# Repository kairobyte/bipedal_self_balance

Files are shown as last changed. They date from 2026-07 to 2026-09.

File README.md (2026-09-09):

# Bipedal Self Balancing Robot

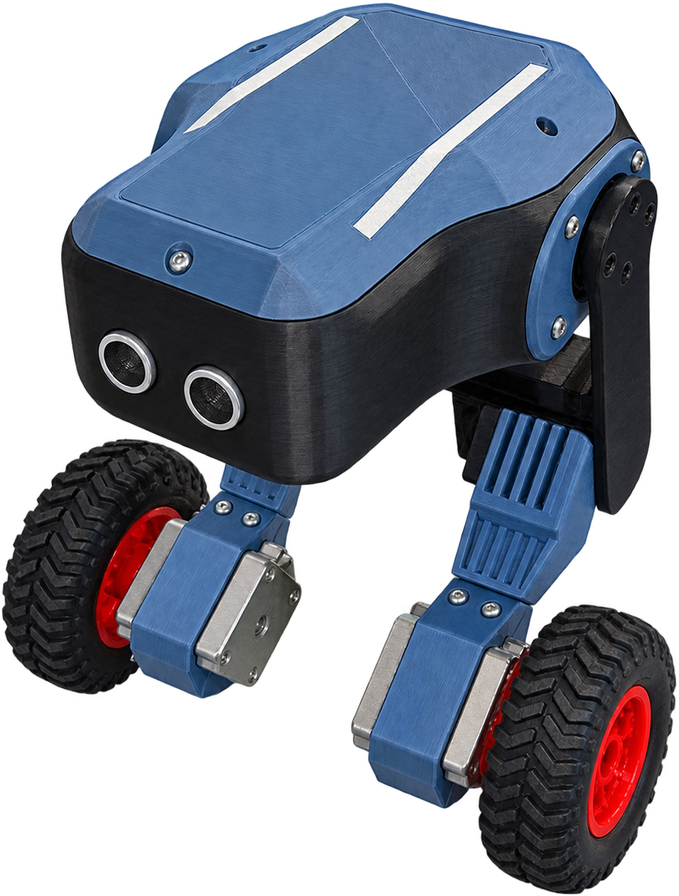
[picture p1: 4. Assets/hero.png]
Self Balancing Robot


## Introduction

This is a self-balancing robot built from scratch, 3D modeled, PCB designed, 3D printed, wired, and tuned entirely as a personal project. It uses an ESP32 as the main controller, dual IMUs for redundancy, stepper-driven wheels, and 2-DOF legs for lean control.

Right now, it balances for a few seconds at a time. It is not perfect, and there are known issues (see [Problems](#problems) below), but the full design, hardware, and firmware are open source here for anyone who wants to build on it, learn from it, or point out what I got wrong.

**Follow the Journey:** [@kairobyte](https://instagram.com/kairobyte) on Instagram.

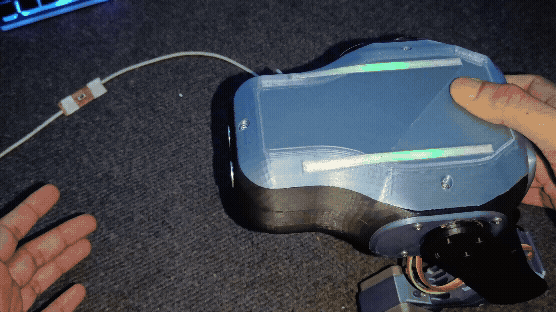
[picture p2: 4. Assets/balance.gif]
Balancing Video


## Sponsors

This build was supported by:

- **[NextPCB](https://www.nextpcb.com/?code=kairobyte)**: PCB manufacturing for this project. Upload your Gerber files, pick your color and thickness, and get an instant quote. Get $30 off your first order.
  
- **[Axis Tech](https://print3dnepal.com/)**: Provided 3D printing filament for this build. They also offer 3D printing services and build a wide range of custom projects. If you're local, check them out.

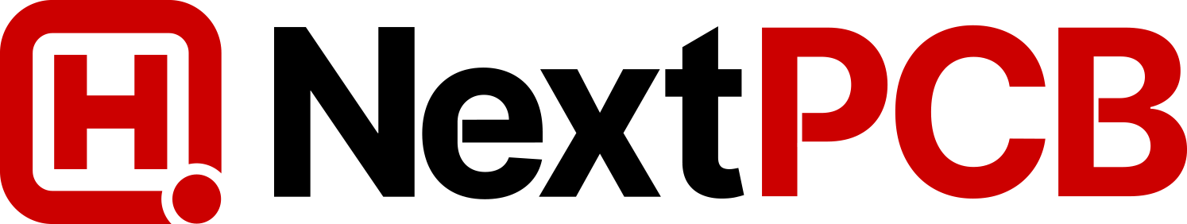
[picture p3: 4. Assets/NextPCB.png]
NextPCB Logo
[](https://www.nextpcb.com/?code=kairobyte)

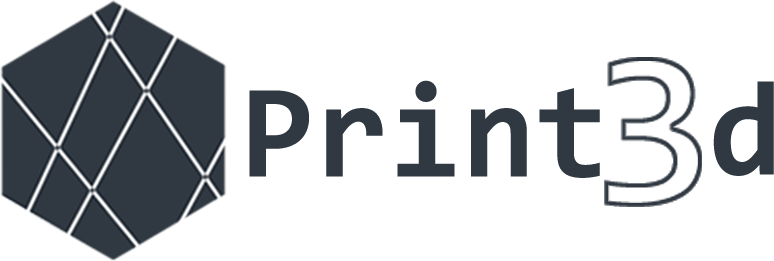
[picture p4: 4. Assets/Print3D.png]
Print3D Logo
[](https://print3dnepal.com/)

## Table of Contents

- [How It Started](#how-it-started)
- [Components](#components)
- [Electronics](#electronics)
- [PCB](#pcb)
- [3D Modelling](#3d-modelling)
- [3D Printing](#3d-printing)
- [Assembly](#assembly)
- [Firmware](#firmware)
- [PID Tuning](#pid-tuning)
- [Problems](#problems)
- [Result](#result)
- [Future Plans](#future-plans)
- [Repository Structure](#repository-structure)
- [License](#license)

## How It Started

- **Idea**: the initial concept for a self-balancing robot.
- **Sketch**: a rough hand sketch of the intended design.
- **Draft 3D Model**: a basic, non-functional 3D model built from the sketch, just for a rough scale and proportion estimate.

<!-- PLACEHOLDER: Sketch photo and early draft 3D model screenshot -->
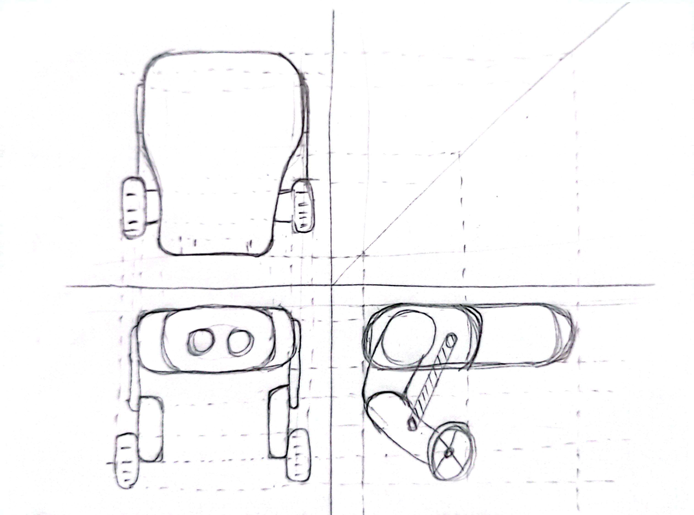
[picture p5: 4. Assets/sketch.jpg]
Rough Sketch
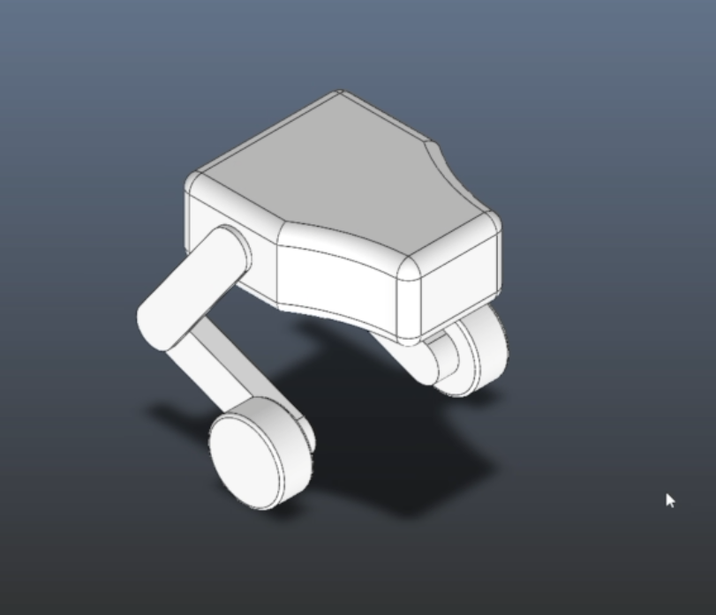
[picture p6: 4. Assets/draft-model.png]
Draft 3D Model


## Components

- **ESP32**: main controller.
- **MPU6050 + MPU9250**: dual IMUs, used for sensor redundancy.
- **A4988 Driver**: used to control the stepper motors.
- **Stepper motors**: used for wheel drive.

> **Note:** If you're building something similar, I would not recommend steppers for the wheels. Go with high-torque BLDC motors instead. Steppers work, but they're not the ideal choice here.

## Electronics

- Two buck converters step down 12V from a 3S LiPo battery, one dedicated to sensors, one dedicated to servos, to keep noisy current draw away from sensor power.
- A capacitor and diode protect the ESP32 from brownouts during high current draw from the servos and steppers.

## PCB

- Selected footprints and components, then built out the full schematic with labeled nets for readability.
- Completed layout and routing.
- Ran the Design Rule Checker (DRC), exported Gerber files, and had the board manufactured through [NextPCB](https://www.nextpcb.com/?code=kairobyte).

<!-- PLACEHOLDER: Schematic screenshot, PCB layout, and final manufactured board photo -->
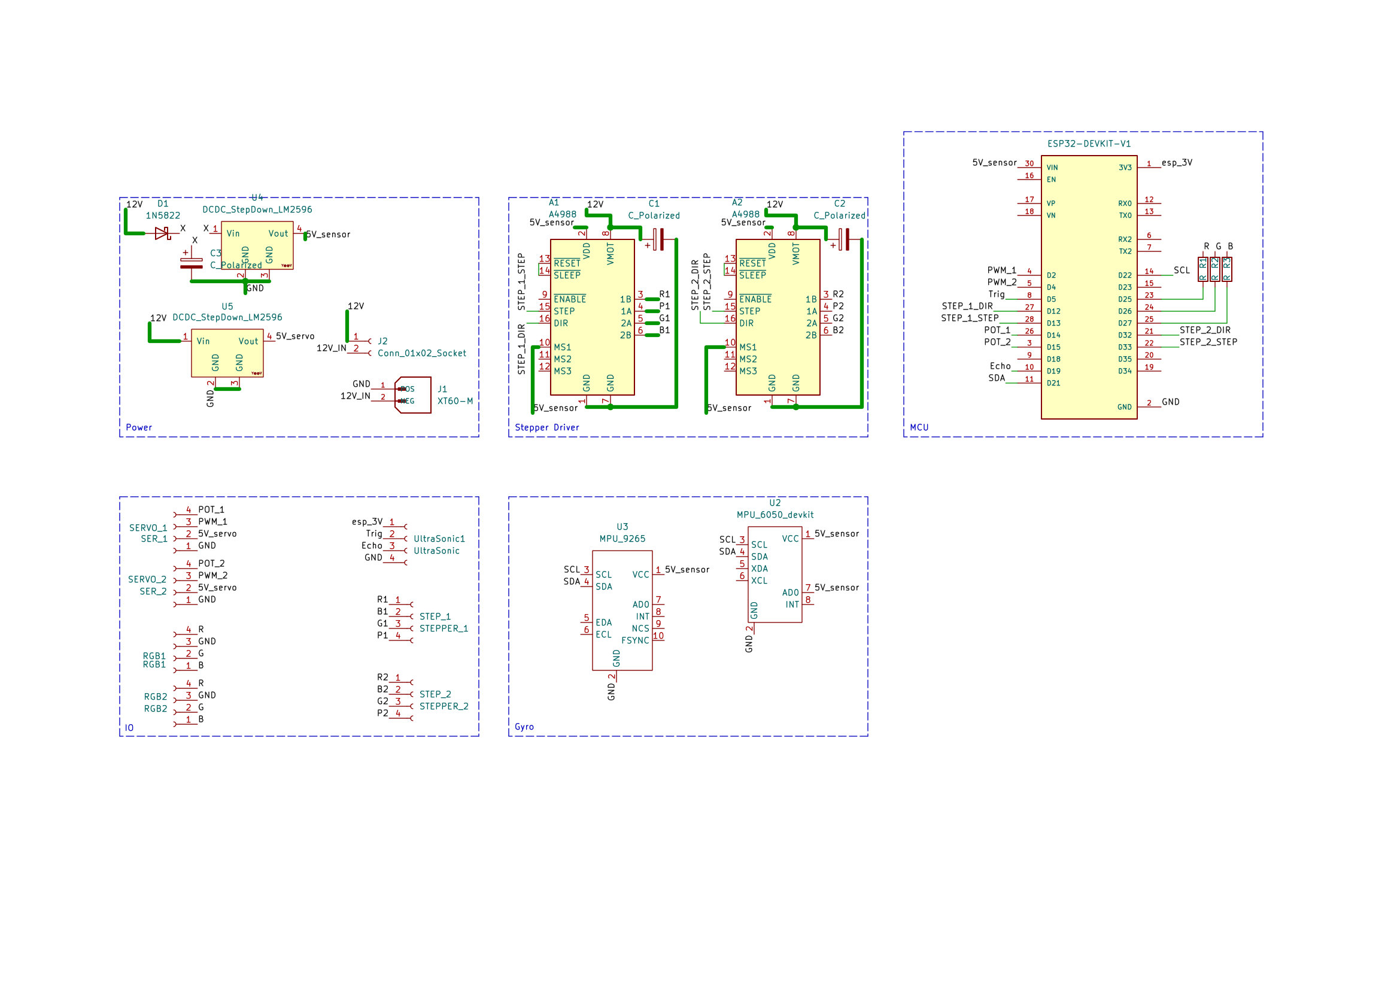
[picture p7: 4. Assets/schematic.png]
Schematic

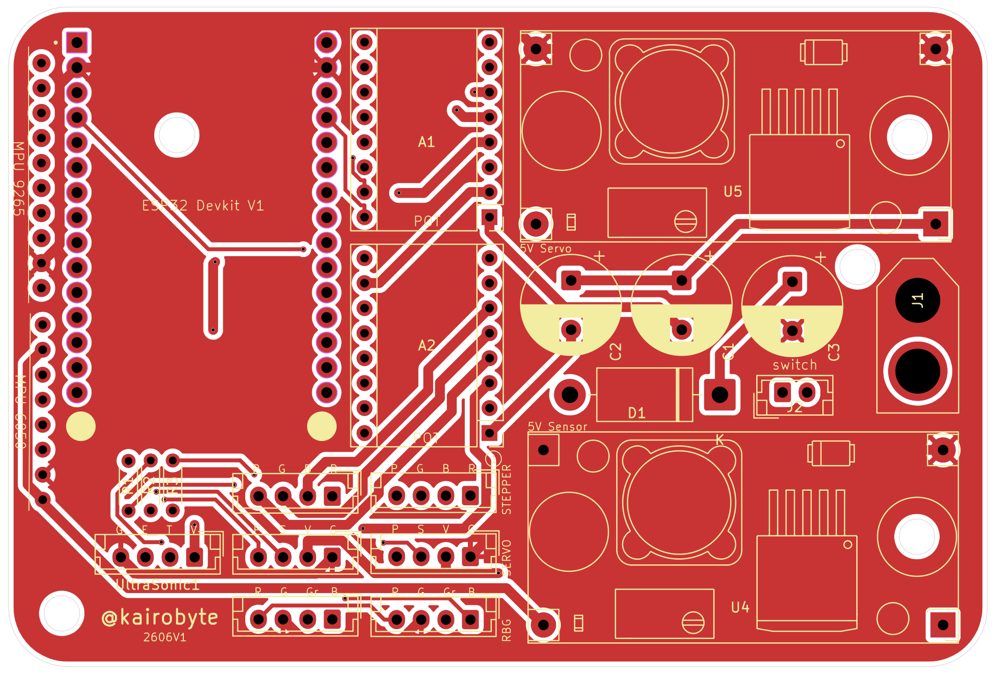
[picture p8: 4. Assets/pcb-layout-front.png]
PCB Layout Front

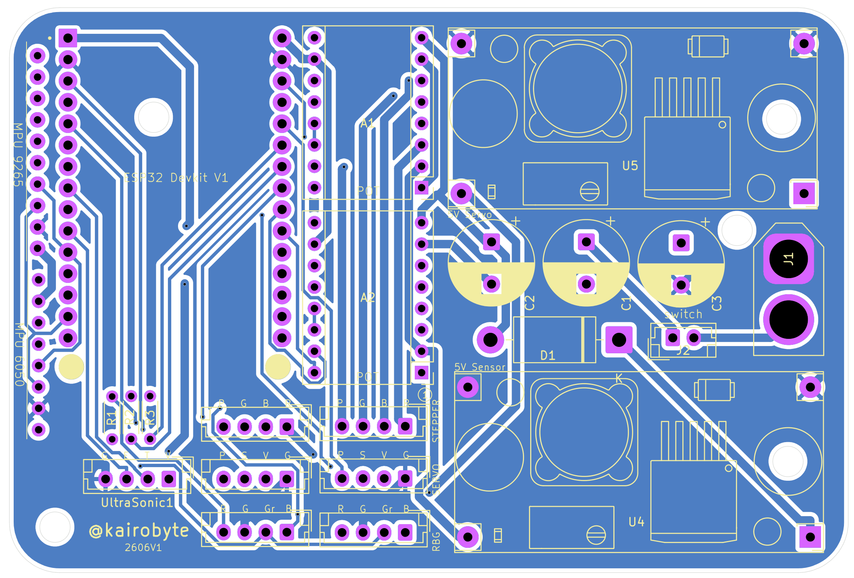
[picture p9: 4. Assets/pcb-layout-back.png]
PCB Layout Back

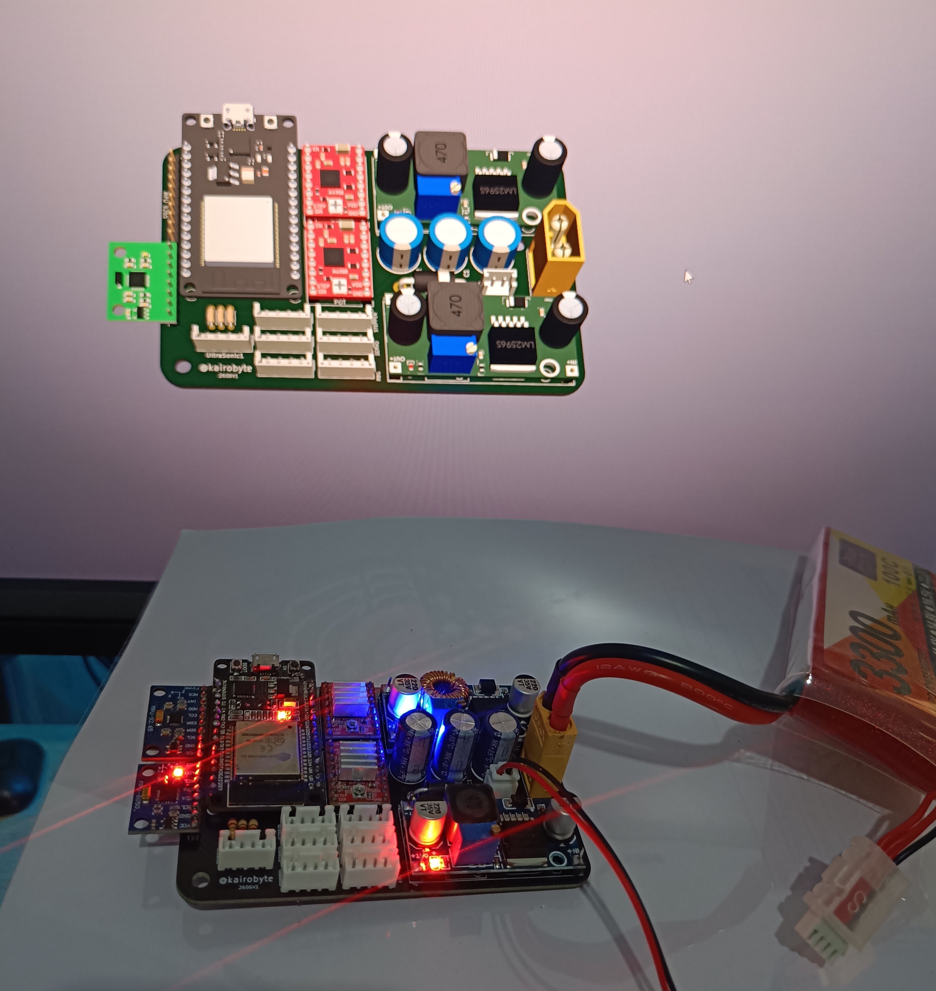
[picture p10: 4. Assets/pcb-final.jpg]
Final PCB


## 3D Modelling

- Modeled in SolidWorks, built bottom-up: stepper holders → legs → base.
- Every part was broken down into basic shapes and built up gradually.
- Designing for 3D printability is a different skill from designing for looks, significant time went into optimizing parts for print rather than just appearance.

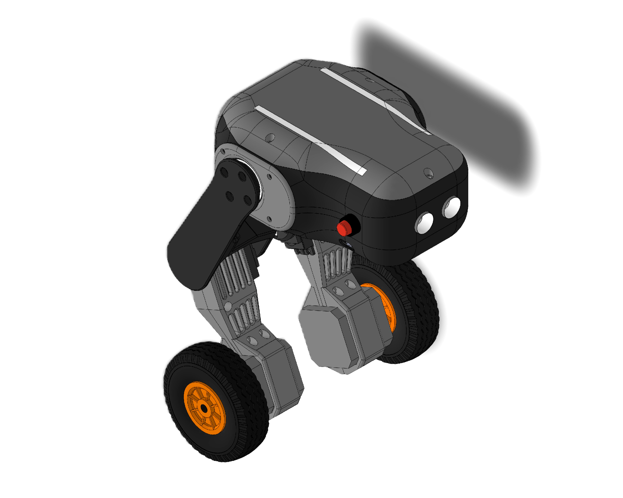
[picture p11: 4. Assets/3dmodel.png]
3D Model


## 3D Printing

- Parts were prepared and arranged in the slicer, then printed over several days.
- Most parts fit together correctly on the first attempt.
- Thanks [Axis Tech](https://print3dnepal.com/) for the Filament Support! 

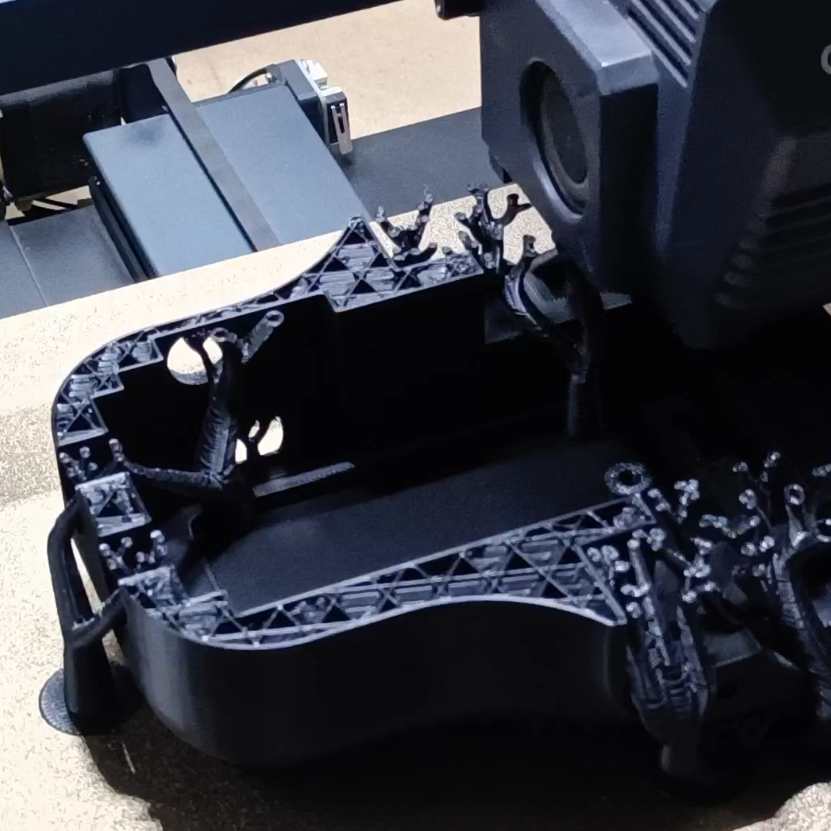
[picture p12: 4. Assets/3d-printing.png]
3D Printing Process


## Assembly

- Assembled all 3D printed parts and completed the wiring.
- The original plan was for 1 degree of freedom (DOF) per leg. When this changed to 2 DOF, extra wires had to be soldered directly onto the ESP32.

> **If you're building this yourself:** finalize your degrees of freedom before finalizing your board layout, to avoid needing extra hand-soldered connections.

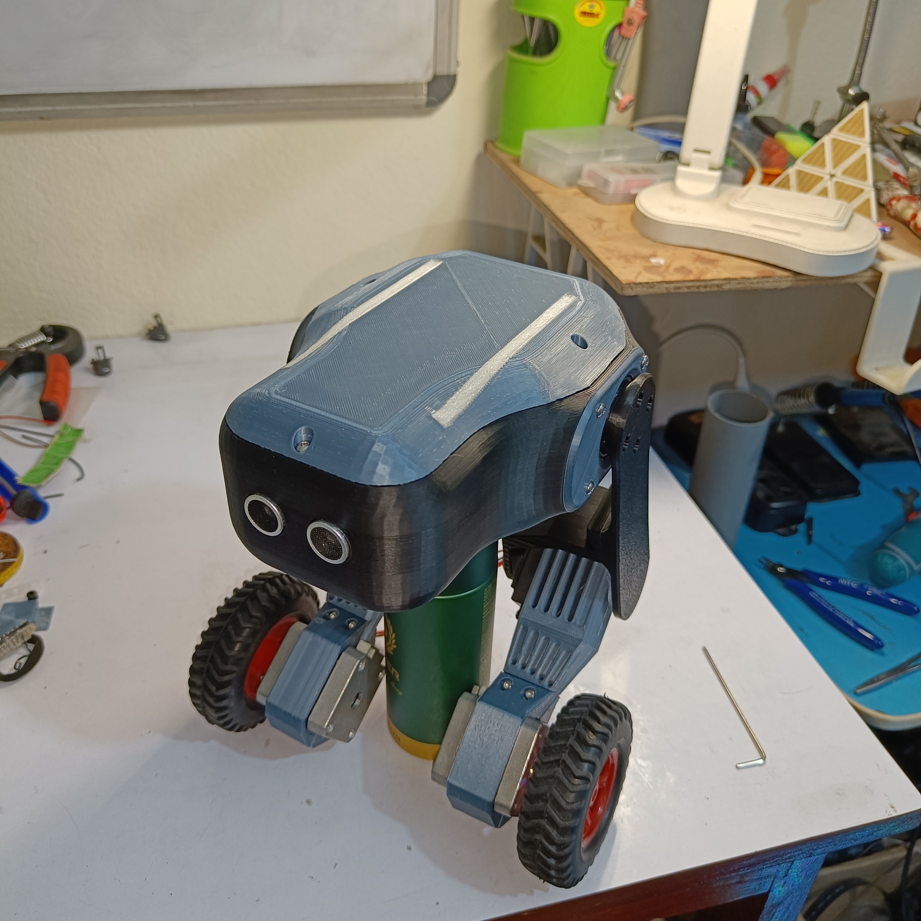
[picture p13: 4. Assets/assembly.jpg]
Fully Assembled Build


## Firmware

- Ran initial test code to confirm all motors, sensors, and RGB indicators were functioning correctly.
- Built a basic PID controller as the first control approach.
- Due to the robot's irregular shape, finding the correct center of mass, and therefore the correct PID set point, was one of the most time-consuming parts of the build.

## PID Tuning

Tuning was the hardest part of this project by a significant margin.

- Initially tuned by manually guessing parameters and reflashing the ESP32 for every change, slow and impractical.
- Updated the firmware to accept tuning parameters over serial and save them without requiring a reflash. A WiFi-based version was attempted but caused repeated ESP32 brownout warnings, so serial was used instead.
- After a couple of days with no visible progress, found that one servo was vibrating irregularly and injecting significant noise into the sensor readings. Replacing that servo noticeably improved stability, though it wasn't a complete fix.
- After continued tuning, the robot balanced for the first time, for a few seconds.
- Found that linear gain increments were not effective, and switched to exponentially increasing gains, along with a low-pass filter applied to key parameters. This slowed the robot's reaction time somewhat, but the control loop still ran at approximately 1kHz, which was fast enough to remain effective.
- Total PID tuning time was a little over a week, including a short break after becoming frustrated with a lack of progress.

## Problems

- **Servo speed**: current servos aren't fast enough to keep up with PID output; the actuator consistently lags behind the commanded position. Needs a faster servo, or a BLDC motor with gear reduction.
- **PID tuning method**: manually guessing parameters is slow and inefficient; a more systematic tuning approach would be better.
- **Vibration/noise**: servo vibration was a major source of sensor noise and nearly derailed the project. Replacing the affected servo helped significantly.
- **Electronics/compute headroom**: the ESP32 currently handles the full control loop, but adding Bluetooth communication (for planned PS4 controller support) is expected to consume enough clock cycles to slow down the PID loop. A better long-term architecture would use a dedicated microcontroller (e.g. STM32) for the core PID loop, with the ESP32 handling WiFi/Bluetooth communication separately, connected via UART.
- **Noise/sensing**: relying on a single sensing source is fragile. A low-pass filter helps smooth spikes, and vibration-dampening rubber mounts can reduce mechanical noise from the steppers.

## Result

The robot currently balances for a few seconds before losing stability. It is a working proof of concept, not a finished product, further tuning and hardware changes are planned for the next phase of this build.

## Future Plans

- **PS4 controller integration** over Bluetooth.
- **Machine learning-based balancing**: exploring whether an ML approach could replace or supplement the PID controller. This is unexplored territory for this project so far.

Follow along on Instagram for more frequent build updates.

## Repository Structure

<!-- PLACEHOLDER: adjust to match your actual repo layout -->
```
├── 1. 3D_Model               # SolidWorks source files and exported STLs
├── 2. PCB_Design             # Schematic, PCB layout, and Gerber files
├── 3. Code                   # ESP32 source code
├── 4. Assets                 # Images used in this README
├── LICENSE
└── README.md
```

## License

This project is open source under the MIT license. See `LICENSE` for details.

##

Send a mail if you want to discuss robotics, design, engineering projects, or anything you think I should build next.
[mail@sushant.uk](mailto:mail@sushant.uk)

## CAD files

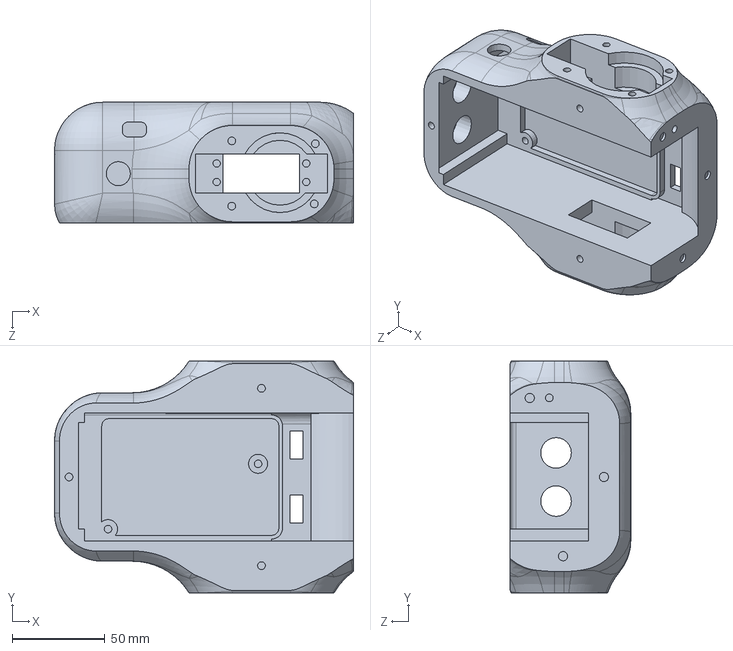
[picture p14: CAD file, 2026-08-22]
1. 3D_Model/2_Body/main.SLDPRT
161.2 x 125.0 x 65.0 mm

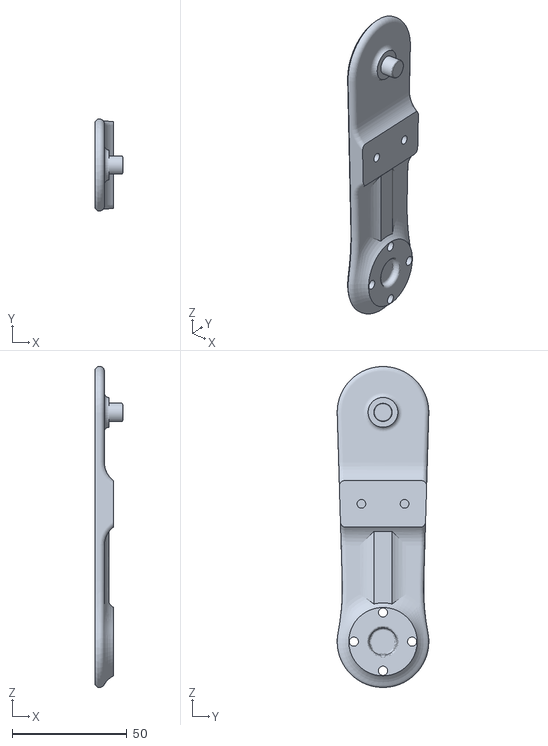
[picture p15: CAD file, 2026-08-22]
1. 3D_Model/3_Upper_Leg/stl/Upper_Leg_CouplerMirror.STL
12.0 x 40.0 x 140.0

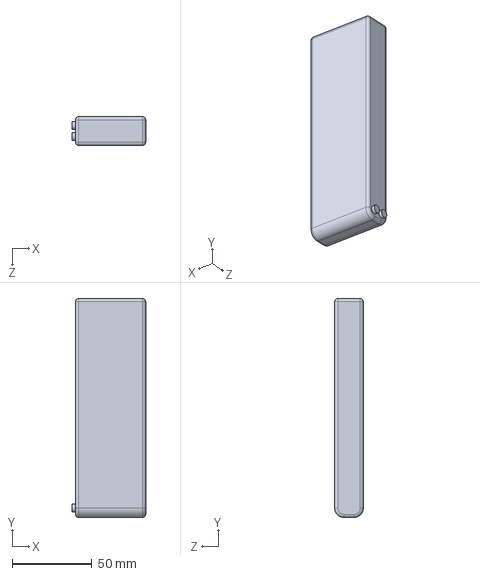
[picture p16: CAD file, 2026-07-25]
1. 3D_Model/7_Accessories/LiPo_Battery.SLDPRT
46.0 x 137.0 x 18.0 mm

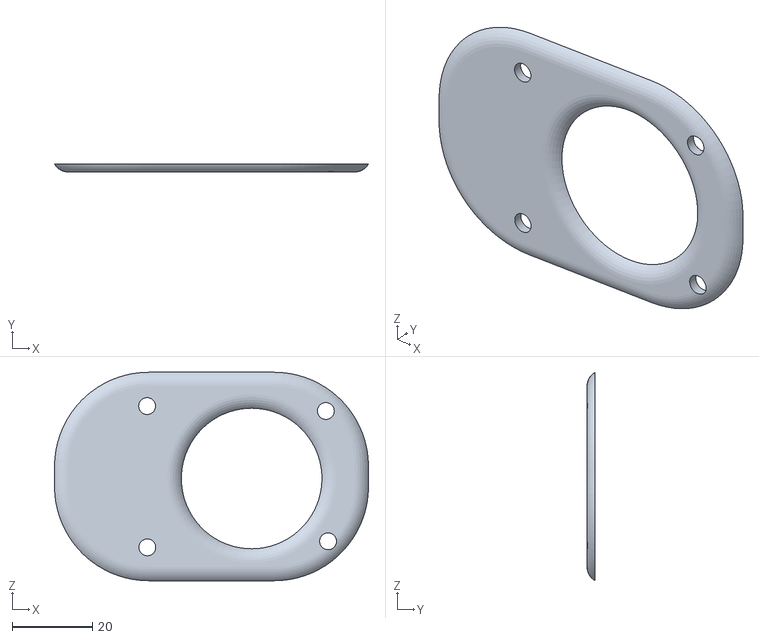
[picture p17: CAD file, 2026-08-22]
1. 3D_Model/8_stl/base_cover_left.STL
78.2 x 2.00 x 51.9

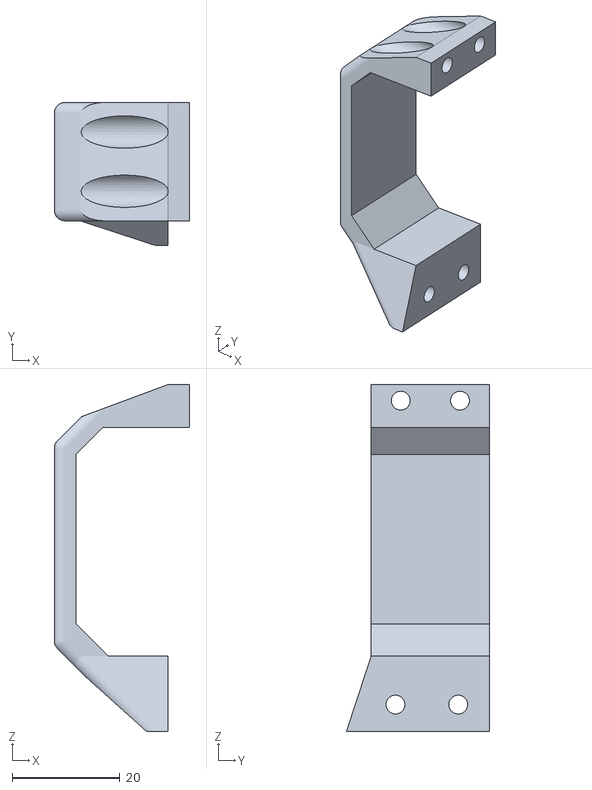
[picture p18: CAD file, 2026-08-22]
1. 3D_Model/8_stl/lower_leg/Lower_Leg_Step_HolderMirror.STL
25.1 x 26.6 x 64.4

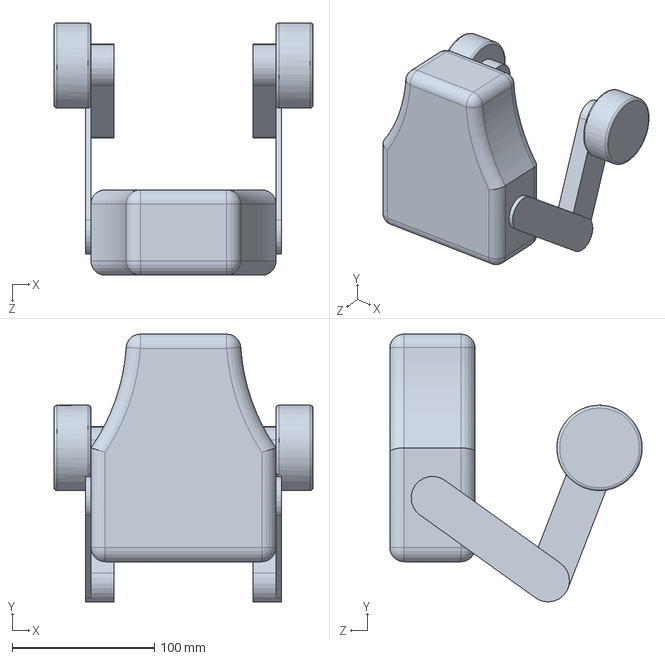
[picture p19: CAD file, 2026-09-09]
1. 3D_Model/basic.SLDPRT
182.0 x 188.2 x 177.4 mm

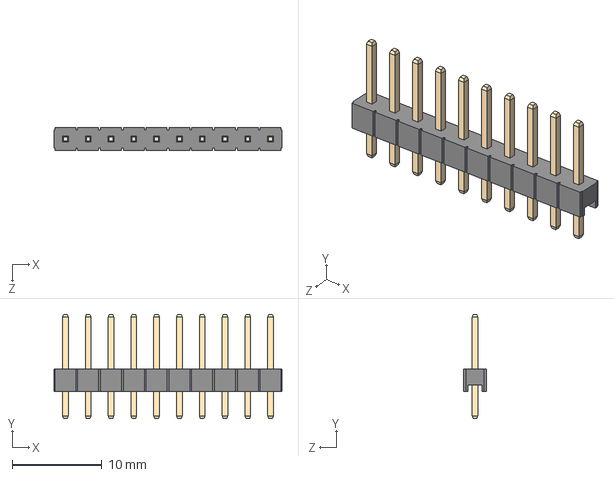
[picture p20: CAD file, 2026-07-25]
2. PCB_Design/0_Custom_Components/10_Pin_Header_Male.STEP
25.4 x 11.6 x 2.54 mm

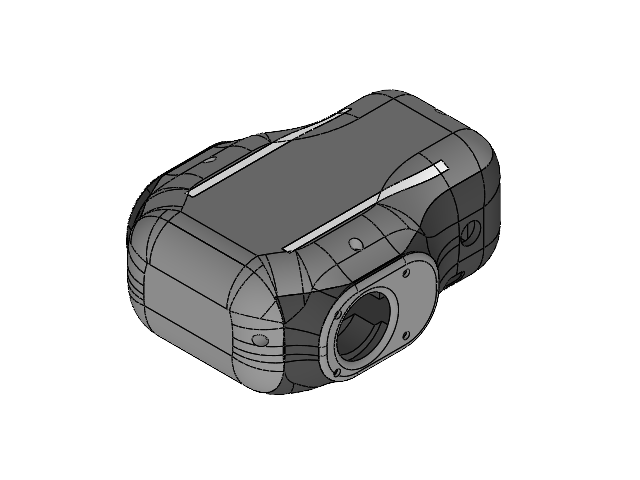
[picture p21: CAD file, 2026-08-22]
1. 3D_Model/2_Body/base.SLDASM
left
back
right
rgb_right
rgb_left
cover_top
main

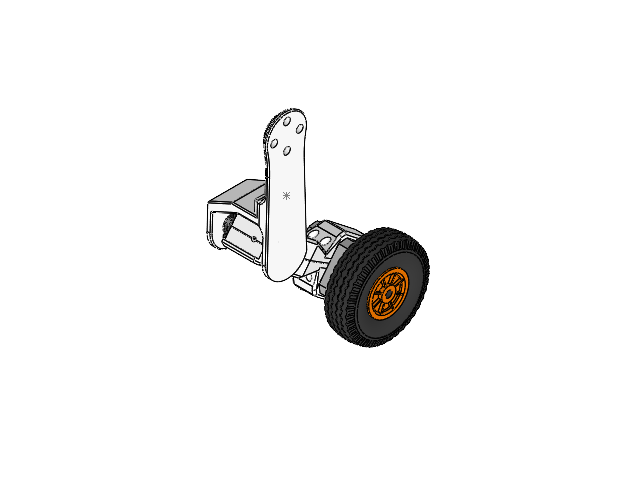
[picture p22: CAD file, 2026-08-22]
1. 3D_Model/3_Upper_Leg/Upper_Leg_Asm.SLDASM
NEMA 17 Motor.step
Scaled_Down_Wheel
MG996R_servo
Lower_Leg_Core
2026-04-08-22-59-56-753.step
2026-04-08-23-06-36-305.step
2026-04-08-23-12-16-735.step
2026-04-08-23-11-13-941.step
2026-04-08-23-50-19-770.step
2026-04-08-23-50-31-866.step
2026-04-08-23-50-38-288.step
2026-04-08-23-50-44-156.step
2026-04-08-23-50-48-451.step
2026-04-08-23-50-52-337.step
2026-04-08-23-59-55-520.step
2026-04-09-00-09-15-499.step
Lower_Leg_Core_Mirror
Lower_Leg_Step_Holder_Mirror
Lower_Leg_Step_Holder
Servo_Star_horn
Upper_Leg_Coupler
Upper_Leg_T

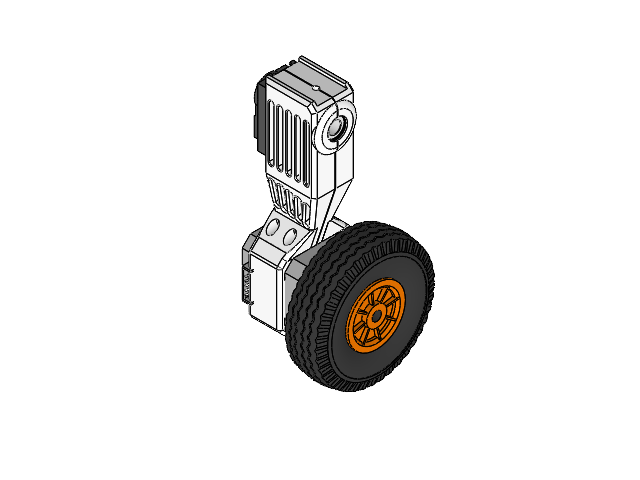
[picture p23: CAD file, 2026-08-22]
1. 3D_Model/4_Lower_Leg/Lower_Leg_Asm.SLDASM
NEMA 17 Motor.step
Scaled_Down_Wheel
MG996R_servo
Lower_Leg_Core
2026-04-08-22-59-56-753.step
2026-04-08-23-06-36-305.step
2026-04-08-23-12-16-735.step
2026-04-08-23-11-13-941.step
2026-04-08-23-50-19-770.step
2026-04-08-23-50-31-866.step
2026-04-08-23-50-38-288.step
2026-04-08-23-50-44-156.step
2026-04-08-23-50-48-451.step
2026-04-08-23-50-52-337.step
2026-04-08-23-59-55-520.step
2026-04-09-00-09-15-499.step
Lower_Leg_Core_Mirror
Lower_Leg_Step_Holder_Mirror
Lower_Leg_Step_Holder

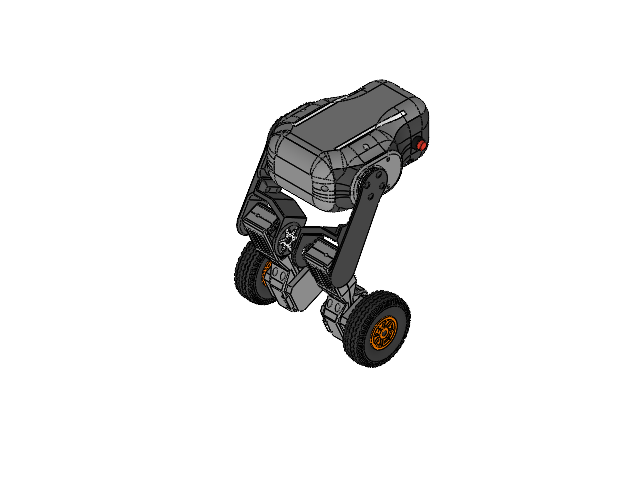
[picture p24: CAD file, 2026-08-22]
1. 3D_Model/main.SLDASM
YAAJ_DCDC_StepDown_LM2596_PinHeaders_cp-0_1.step x 2
JST_B4B_EH_A_1.step x 7
R_Axial_DIN0204_L36mm_D16mm_P508mm_Horizontal_1.step x 3
DS1021-1_10SF11_1.step
CP_Radial_D100mm_P500mm_1.step x 3
D_DO-201AD_P15.24mm_Horizontal-1_1.step
JST_B2B_EH_A_1.step
XT60 male v9_1.step
Document_1.step x 2
ESP32-DEVKIT-V1-2_1.step
Base_1.step
pin header_1.step x 8
sensor chip_1.step
S2NH chip_1.step
Resistor small_1.step x 6
Resistor small black_1.step x 4
Small LED_1.step
Resistor black_1.step
Controller_Board_PCB_1.step
HC-SR04
LiPo_Battery
68062RS.stp x 2
Servo_Horn x 2
coupler_servo_side x 2
PushButtonSwitch.step
NEMA 17 Motor.step
Scaled_Down_Wheel
MG996R_servo x 3
Lower_Leg_Core
2026-04-08-22-59-56-753.step
2026-04-08-23-06-36-305.step
2026-04-08-23-12-16-735.step
2026-04-08-23-11-13-941.step
2026-04-08-23-50-19-770.step
2026-04-08-23-50-31-866.step
2026-04-08-23-50-38-288.step
2026-04-08-23-50-44-156.step
2026-04-08-23-50-48-451.step
2026-04-08-23-50-52-337.step
2026-04-08-23-59-55-520.step
2026-04-09-00-09-15-499.step
Lower_Leg_Core_Mirror
Lower_Leg_Step_Holder_Mirror
Lower_Leg_Step_Holder
Servo_Star_horn
Upper_Leg_Coupler
Upper_Leg_T
left
back
right
rgb_right
rgb_left
cover_top
main
NEMA 17 Motor.stepMirror
Scaled_Down_WheelMirror
MG996R_servoMirror
Lower_Leg_CoreMirror
2026-04-08-22-59-56-753.stepMirror
2026-04-08-23-06-36-305.stepMirror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

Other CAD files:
1. 3D_Model/3_Upper_Leg/mirrored_components/Upper_Leg_AsmMirror.SLDASM
1. 3D_Model/4_Lower_Leg/MirrorLower_Leg_Asm.SLDASM
1. 3D_Model/3_Upper_Leg/mirrored_components/Lower_Leg_AsmMirror.SLDASM
1. 3D_Model/3_Upper_Leg/mirrored_components/608RS Steel Ball Bearing.stepMirror.SLDASM
1. 3D_Model/1_External_Components/MirrorServo_Star_horn.SLDPRT
1. 3D_Model/3_Upper_Leg/mirrored_components/2026-04-08-23-50-31-866.stepMirror.SLDPRT
1. 3D_Model/8_stl/upper_leg/Upper_Leg_T.STL
1. 3D_Model/1_External_Components/608RS Steel Ball Bearing.step
1. 3D_Model/1_External_Components/68062RS.stp
1. 3D_Model/1_External_Components/85mm_Wheel.SLDPRT
1. 3D_Model/1_External_Components/HC-SR04.SLDPRT
1. 3D_Model/1_External_Components/MG996R_servo.SLDPRT
1. 3D_Model/1_External_Components/MirrorMG996R_servo.SLDPRT
1. 3D_Model/1_External_Components/MirrorNEMA 17 Motor.step
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

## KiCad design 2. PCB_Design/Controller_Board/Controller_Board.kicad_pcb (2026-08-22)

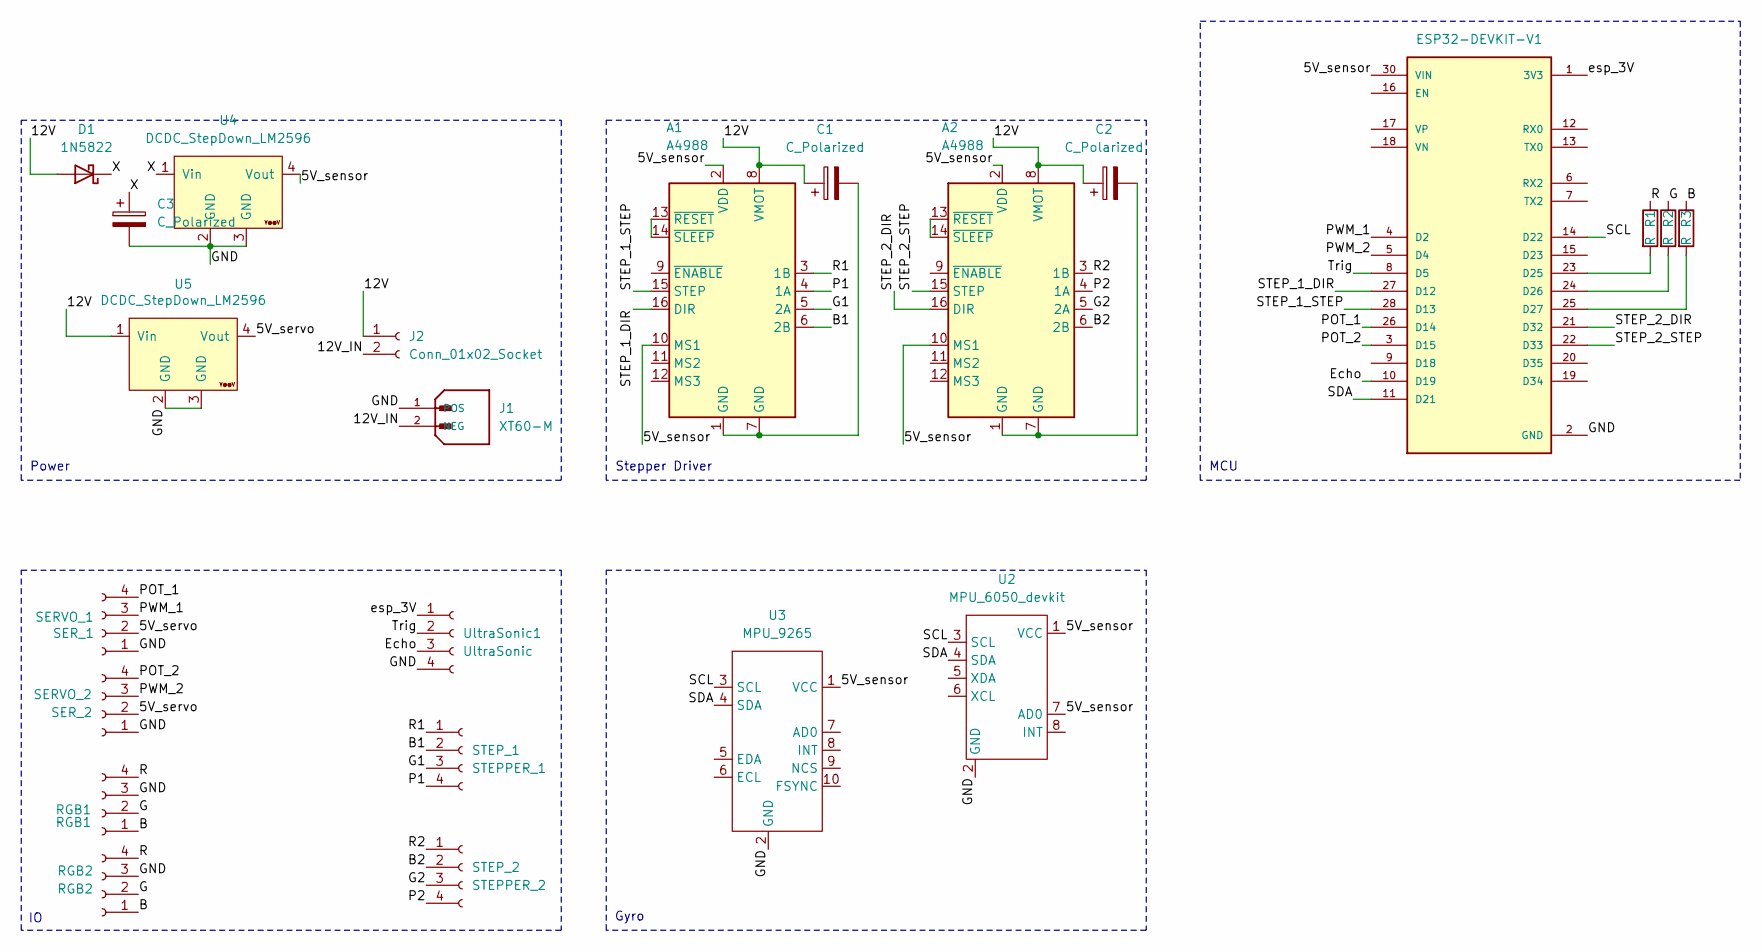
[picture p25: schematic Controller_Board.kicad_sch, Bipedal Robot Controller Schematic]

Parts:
A1, A2: A4988; Pololu_Breakout-16_15.2x20.3mm
C1, C2, C3: C_Polarized; CP_Radial_D10.0mm_P5.00mm
D1: 1N5822; D_DO-201AD_P15.24mm_Horizontal
J1: XT60-M; AMASS_XT60-M_1x02_P7.20mm_Vertical
J2: Conn_01x02_Socket; JST_EH_B2B-EH-A_1x02_P2.50mm_Vertical
R1, R2, R3: R; R_Axial_DIN0204_L3.6mm_D1.6mm_P5.08mm_Horizontal
RGB1: RGB1; JST_EH_B4B-EH-A_1x04_P2.50mm_Vertical
RGB2: RGB2; JST_EH_B4B-EH-A_1x04_P2.50mm_Vertical
SER_1: SERVO_1; JST_EH_B4B-EH-A_1x04_P2.50mm_Vertical
SER_2: SERVO_2; JST_EH_B4B-EH-A_1x04_P2.50mm_Vertical
STEP_1: STEPPER_1; JST_EH_B4B-EH-A_1x04_P2.50mm_Vertical
STEP_2: STEPPER_2; JST_EH_B4B-EH-A_1x04_P2.50mm_Vertical
U1: ESP32-DEVKIT-V1; MODULE_ESP32_DEVKIT_V1; PARTREV N/A
U2: MPU_6050_devkit; mpu_6050_custom
U3: MPU_9265; mpu_9265
U4, U5: DCDC_StepDown_LM2596; YAAJ_DCDC_StepDown_LM2596
UltraSonic1: UltraSonic; JST_EH_B4B-EH-A_1x04_P2.50mm_Vertical

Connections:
/5V_sensor: A1.2 (VDD), A1.10 (MS1), A2.2 (VDD), A2.10 (MS1), U1.30 (VIN), U2.1 (VCC), U2.7 (AD0), U3.1 (VCC), U4.4 (Vout)
/5V_servo: SER_1.2, SER_2.2, U5.4 (Vout)
/12V: A1.8 (VMOT), A2.8 (VMOT), C1.1, C2.1, D1.2 (A), J2.1, U5.1 (Vin)
/12V_IN: J1.2 (NEG), J2.2
/B: R3.1, RGB1.1, RGB2.1
/B1: A1.6 (2B), STEP_1.2
/B2: A2.6 (2B), STEP_2.2
/Echo: U1.10 (D19), UltraSonic1.3
/G: R2.1, RGB1.2, RGB2.2
/G1: A1.5 (2A), STEP_1.3
/G2: A2.5 (2A), STEP_2.3
/P1: A1.4 (1A), STEP_1.4
/P2: A2.4 (1A), STEP_2.4
/POT_1: SER_1.4, U1.26 (D14)
/POT_2: SER_2.4, U1.3 (D15)
/PWM_1: SER_1.3, U1.4 (D2)
/PWM_2: SER_2.3, U1.5 (D4)
/R: R1.1, RGB1.4, RGB2.4
/R1: A1.3 (1B), STEP_1.1
/R2: A2.3 (1B), STEP_2.1
/SCL: U1.14 (D22), U2.3 (SCL), U3.3 (SCL)
/SDA: U1.11 (D21), U2.4 (SDA), U3.4 (SDA)
/STEP_1_DIR: A1.16 (DIR), U1.27 (D12)
/STEP_1_STEP: A1.15 (STEP), U1.28 (D13)
/STEP_2_DIR: A2.16 (DIR), U1.21 (D32)
/STEP_2_STEP: A2.15 (STEP), U1.22 (D33)
/Trig: U1.8 (D5), UltraSonic1.2
/X: C3.1, D1.1 (K), U4.1 (Vin)
/esp_3V: U1.1 (3V3), UltraSonic1.1
GND: C3.2, J1.1 (POS), RGB1.3, RGB2.3, SER_1.1, SER_2.1, U1.2 (GND), U1.29 (GND), U2.2 (GND), U3.2 (GND), U4.2 (GND), U4.3 (GND), U5.2 (GND), U5.3 (GND), UltraSonic1.4
unnamed: A1.1 (GND), A1.7 (GND), C1.2
unnamed: A1.13 (~RESET), A1.14 (~SLEEP)
unnamed: A2.1 (GND), A2.7 (GND), C2.2
unnamed: A2.13 (~RESET), A2.14 (~SLEEP)
unnamed: R1.2, U1.23 (D25)
unnamed: R2.2, U1.24 (D26)
unnamed: R3.2, U1.25 (D27)

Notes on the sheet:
Power
Stepper Driver
MCU
Gyro

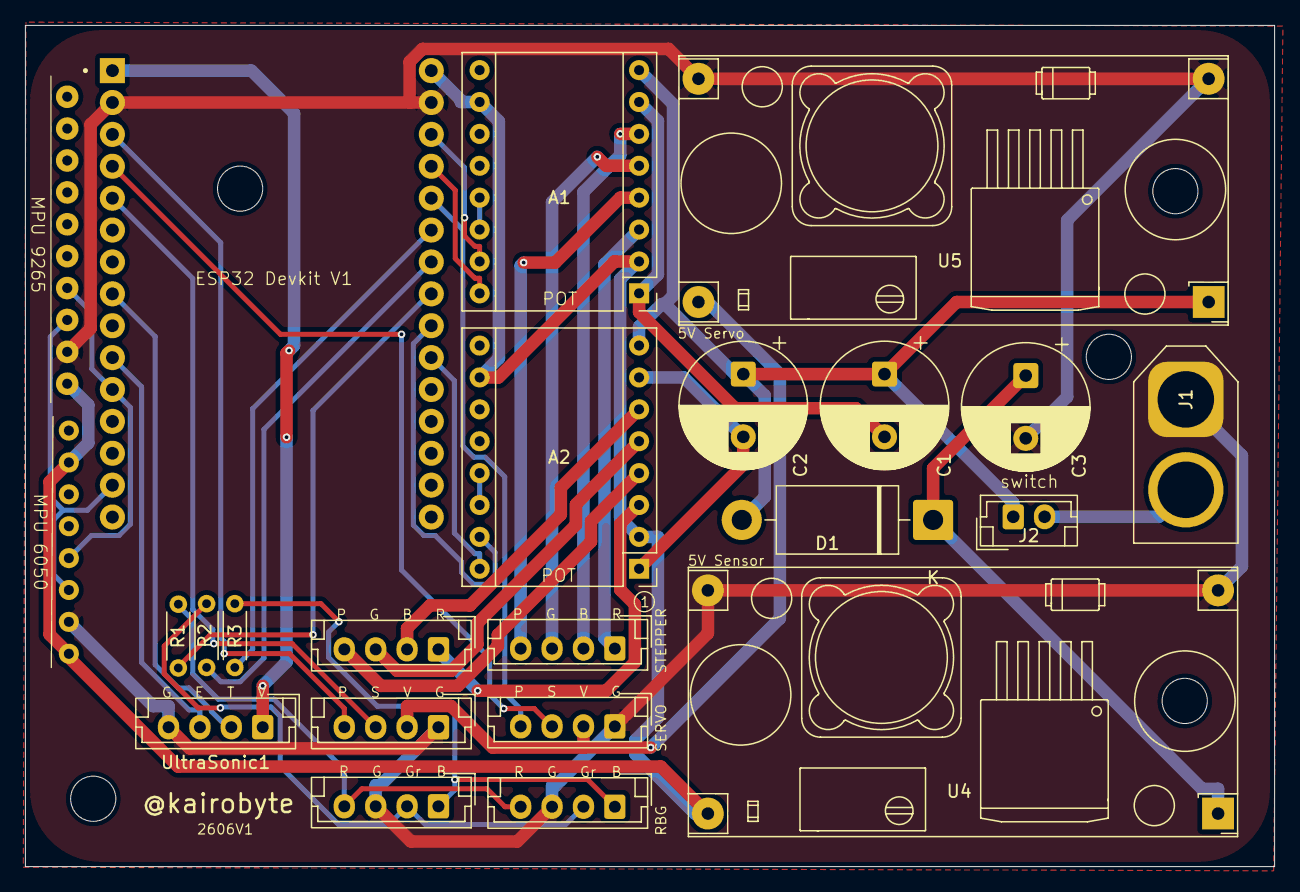
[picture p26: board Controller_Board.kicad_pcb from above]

Board: 2 copper layers, 99.5 x 67.0 mm, 23 parts (0 on the bottom side), 37 nets.

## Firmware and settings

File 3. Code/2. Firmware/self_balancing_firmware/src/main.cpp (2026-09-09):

#include <Arduino.h>
#include "stepper.h"
#include "led.h"
#include "servo.h"
#include "gyro.h"    
#include "tuning.h"

const float SERVO_BASE_1 = servo1; 
const float SERVO_BASE_2 = servo2;

float command = 0;
float integral = 0;
float lastAngle = SET_POINT;
float servoChange = 0.0;
float lastError = 0.0;
float lastCommand =0.0;

unsigned long lastControlTime = 0;
unsigned long last_time = 0;

void setup() {
	Serial.begin(115200);
	mpu_setup();
	stepper_setup();
	servo_setup();
	rgb_setup();
	tuning_setup();

	// servo_move(55, 45, 40, 140);
	servo_move(servo1, servo2, servo3, servo4);
	set_rgb(0, 255, 0);
	Serial.println("Setup Done.");
}

// @CodeScene(disable:"Complex Method")
void loop() {
	unsigned long now = micros();
	tuning_poll();

	if (now - lastControlTime >= (unsigned long)CONTROL_INTERVAL_US) {
		float dt = (now - lastControlTime) / 1000000.0f;
		lastControlTime = now;
		if (dt <= 0) dt = (unsigned long)CONTROL_INTERVAL_US / 1000000.0f;

		float angle = get_angle();
		float error = angle - SET_POINT;
		error = ke * error + (1-ke)*lastError;
		lastError = error;
		if (fabs(error) < DEADBAND) error = 0;

		integral += error * dt;
		integral = constrain(integral, -50.0f, 50.0f);

		float derivative = (angle - lastAngle) / dt;
		lastAngle = angle;

		float sign = (error > 0) ? 1.0f : (error < 0 ? -1.0f : 0.0f);
		float pTerm = kp * error + kp_boost * error * error * sign;
		
		command = pTerm + ki * integral - kd * derivative; 

		if (error != 0 && fabs(command) > 0 && fabs(command) < MIN_SPEED) {
			command = (command > 0) ? MIN_SPEED : -MIN_SPEED;
		} else if (error == 0) {
			command = 0;
		}
		command = command*kc + (1-kc)*lastCommand;
		lastCommand = command;
		command = constrain(command, -MAX_COMMAND, MAX_COMMAND);
		setStepperSpeed((int)command);

		float legLean = constrain(LEAN_GAIN * error, -LEAN_LIMIT, LEAN_LIMIT);
		float newServo1 = constrain(servo1 + legLean, 0, 180);
		float newServo2 = constrain(servo2 + legLean, 0, 180);
		servo_move(newServo1, newServo2, servo3, servo4);
		// Serial.print("Angle Max=");
		// Serial.print(90);
		// Serial.print(",");
		// Serial.print("Angle Min");
		// Serial.print(0);
		// Serial.print(",");
		// Serial.print("Angle=");
		// Serial.print(angle);
		// Serial.print(",");
		// Serial.print("SetPoint=");
		// Serial.print(SET_POINT);
		// Serial.print(",");
		// Serial.print("Error");
		// Serial.print(error);
		// Serial.print(",");
		// Serial.print("Command=");
		// Serial.print(command);
		// Serial.println();
	}

	stepStepper();
}

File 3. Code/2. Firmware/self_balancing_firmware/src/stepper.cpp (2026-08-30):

#include "stepper.h"

#define dir_pin_l 12
#define step_pin_l 13

#define dir_pin_r 32
#define step_pin_r 33

int init_speed = 1000;

AccelStepper stepper_left(AccelStepper::DRIVER, step_pin_l, dir_pin_l);
AccelStepper stepper_right(AccelStepper::DRIVER, step_pin_r, dir_pin_r);

void stepper_setup() {
	stepper_left.setMaxSpeed(3000);
	stepper_right.setMaxSpeed(3000);
	stepper_left.setSpeed(init_speed);
	stepper_right.setSpeed(init_speed);
}

void runStepper(int speed){
	stepper_left.setSpeed(-speed);
	stepper_right.setSpeed(speed);
	stepper_left.runSpeed();
	stepper_right.runSpeed();
} 

void setStepperSpeed(int speed){
	stepper_left.setSpeed(-speed);
	stepper_right.setSpeed(speed);
}

void stepStepper(){
	stepper_left.runSpeed();
	stepper_right.runSpeed();
} 

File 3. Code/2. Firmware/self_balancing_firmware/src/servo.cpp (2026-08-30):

#include "servo.h"

const int left_up_pin = 18;
const int right_up_pin = 16;
const int right_low_pin = 2;
const int left_low_pin = 4;

Servo left_up; //LU
Servo right_up; //RU
Servo right_low; //RL
Servo left_low; //LL

void servo_setup(){
	left_up.attach(left_up_pin, 544, 2400); 
	right_up.attach(right_up_pin, 544, 2400);
	right_low.attach(right_low_pin, 544, 2400);
	left_low.attach(left_low_pin, 544, 2400);
	// left_low.attach(left_low_pin, 544, 2400);
}

void servo_move(int a, int b, int c, int d){
	left_up.write(a);
	right_up.write(b);
	right_low.write(c);
	left_low.write(d);
}

// default pose = 55, 45, 40, 140

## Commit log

2026-06-20 initial commit from new init
    [608RS Steel Ball Bearing.step, 85mm_Wheel.SLDPRT, A4988-Stepper-Driver-WithPins.stp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]
2026-07-04 working on 3d model now
    [Controller_Board-B_Cu.gbr, Controller_Board-B_Mask.gbr, Controller_Board-B_Paste.gbr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]
2026-07-07 lower leg initial design 01
    [Controller_Board.kicad_pcb, Controller_Board.kicad_sch, Lower_Leg_Asm.SLDASM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]
2026-07-25 added initial tests code
    [10_Pin_Header_Male.STEP, Controller_Board.kicad_pcb, LiPo_Battery.SLDPRT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]
2026-08-22 before developing firmware
    [2026-04-08-22-59-56-753.stepMirror.SLDPRT, 2026-04-08-23-06-36-305.stepMirror.SLDPRT, 2026-04-08-23-11-13-941.stepMirror.SLDPRT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]
2026-08-22 before PID
2026-09-09 basic functions working
    [basic.SLDPRT]
2026-09-09 Update README with Instagram link and PCB details
    Added social media link and improved PCB section with manufacturer reference.
